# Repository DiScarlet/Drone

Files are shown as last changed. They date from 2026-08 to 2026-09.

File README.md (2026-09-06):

# Custom Drone
This is the custom 11 inch drone that I have been designing from scratch over the last few months.

Inspect the 3D Model Here: [autode.sk/4qQeJi8](https://autode.sk/4qQeJi8)

Concept Board Link: [app.idroo.com/boards/iBzdX5M0Z2](https://app.idroo.com/boards/iBzdX5M0Z2)

the goal is to make a relatively compact quadcopter that can carry a bunch of sensors and a jetson computer while still having enough thrust and flight time to actually be useful.

the electrycal connections concept was done i KiCad and the whole frame is designed in Fusion 360 and im planning to manufacture the main structural parts from carbon fiber.

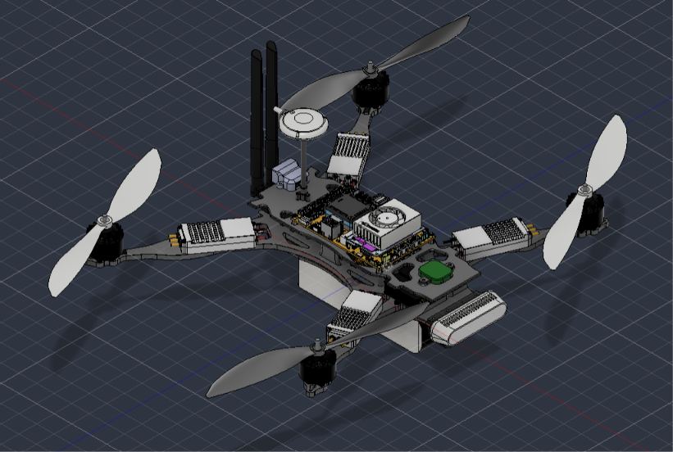
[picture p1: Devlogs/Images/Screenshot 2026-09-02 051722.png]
Full drone


## Reviewer note

Hey! If you're reviewing this, the main thing I would look at is the CAD design and how the different parts were integrated together. I tried to design the frame around the actual components instead of just making something that looks cool.

There are probably still some things I could improve, especially around weight, rigidity and aerodynamics, but I wanted to get a complete working design first and then improve it from there. Thanks for checking it out! :)

## components?

the drone is designed around:

- Pixhawk Jetson Baseboard
- Jetson Orin NX/Nano
- Holybro M10 GPS + IST8310 compass
- 4 individual ESCs
- 4 motors
- 11–12" propellers
- 6S battery
- depth camera
- 4 LiDAR sensors
- 4G communication

the idea is to have enough room for all of this without making the frame unnecessarily huge or heavy.

## why did i make this?

i wanted to build a drone where i actually designed the frame myself instead of just buying a random frame and putting electronics on it.

there were also a bunch of things i wanted to experiment with, mainly:

- custom carbon fiber frame design
- center of mass optimization
- propeller clearance
- modular arm mounting
- sensor placement
- aerodynamic testing
- fitting a jetson computer onto a relatively small drone

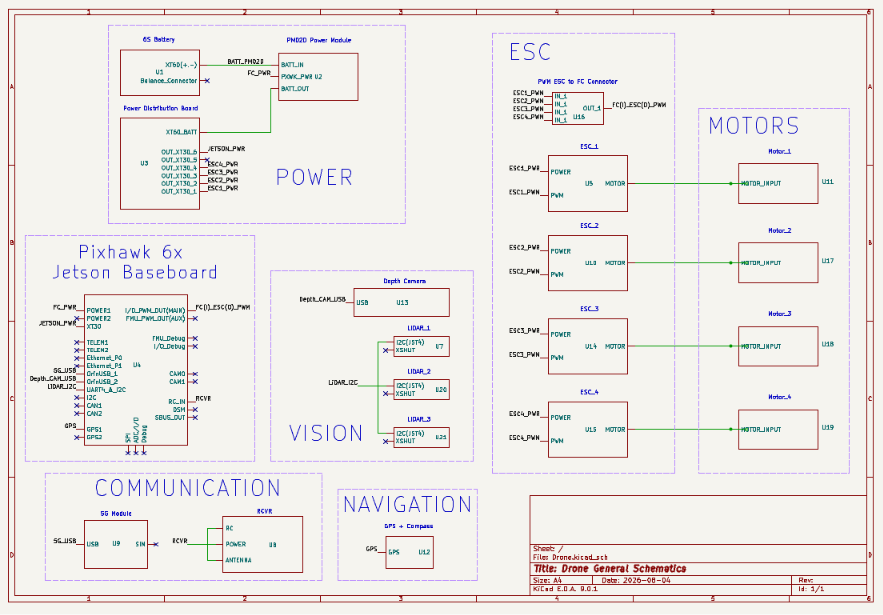
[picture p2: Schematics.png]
Schematics


also i just wanted to see how far i could take a drone design in CAD before actually building it.

## how i made it

most of the mechanical design was done in **Autodesk Fusion 360**.

i started with the overall frame dimensions and then worked from the propellers inward. this ended up being way better than trying to randomly draw the arms first because propeller clearance becomes a huge pain very quickly.

the frame went through quite a few versions.

at one point i accidentally designed a normal X layout when i was actually trying to make a deadcat layout, which was fun to figure out later.

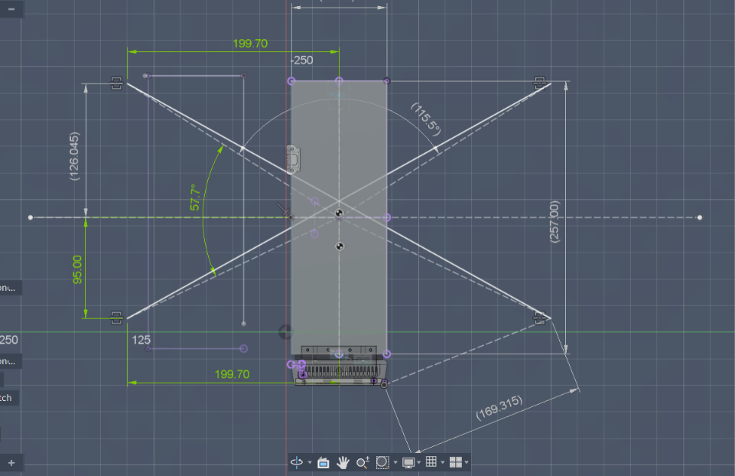
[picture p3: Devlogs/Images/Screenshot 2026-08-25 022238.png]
X


after that i worked on the arm angles, motor positions, camera clearance and center of mass.

the center of mass was another thing that took way more work than i expected. i used the actual component masses where i could and adjusted the material densities in Fusion so the CAD model would represent the real components better.

i also made the arm sections modular so they can be removed/swapped without having to completely take apart the whole drone.

## frame design

the frame has separate top, bottom and arm planes.

the bottom section carries a lot of the main structure and battery, while the top section is mainly for electronics and mounting.

i added mounting points for the different components and also added holes in the top plate to remove some material and hopefully improve airflow.

the arms also got redesigned after i realized i had completely forgotten about the ESCs.

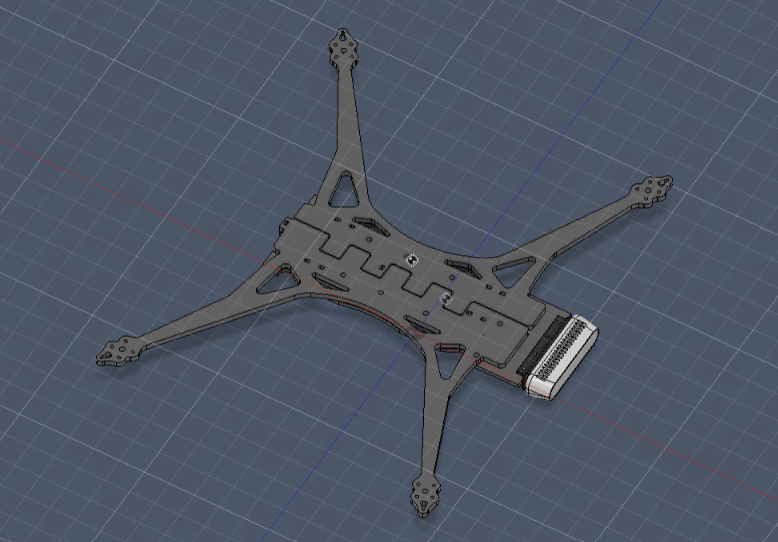
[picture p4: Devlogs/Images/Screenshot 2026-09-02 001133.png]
epic fail


yes.

i designed the arms and then remembered that the ESCs probably needed somewhere to go.

so i had to redo part of the arm design and integrate the ESC mounting properly.

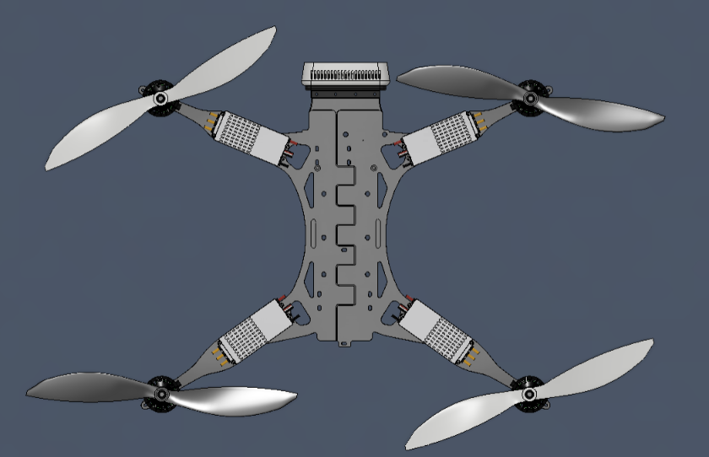
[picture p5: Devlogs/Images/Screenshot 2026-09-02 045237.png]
top view


## center of mass

the current estimated drone mass is around **3.2 kg** including some extra allowance for wiring, heatshrink and other small stuff.

i was aiming for roughly a **2.3:1 thrust-to-weight safety ratio**, which gives a target total thrust of around 7.4 kg.

that means around 1.9–2.0 kg of thrust per motor.

the battery position is also being used as one of the main ways to adjust the final center of mass instead of just adding random ballast weights.

## CFD

i am also testing the final drone design using CFD. But more experimentation are for the future.

## some pictures

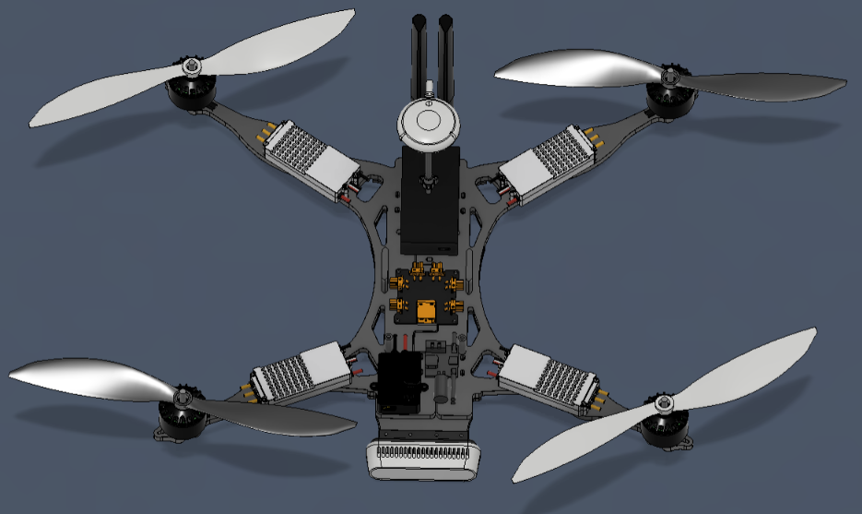
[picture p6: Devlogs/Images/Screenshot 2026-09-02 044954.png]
top


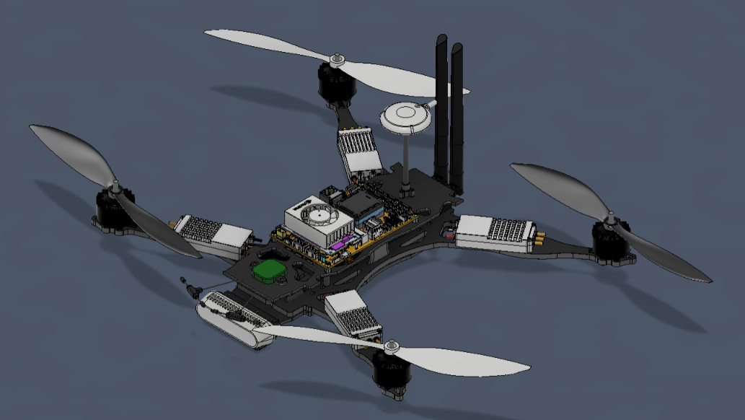
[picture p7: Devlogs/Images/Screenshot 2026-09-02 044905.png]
side view


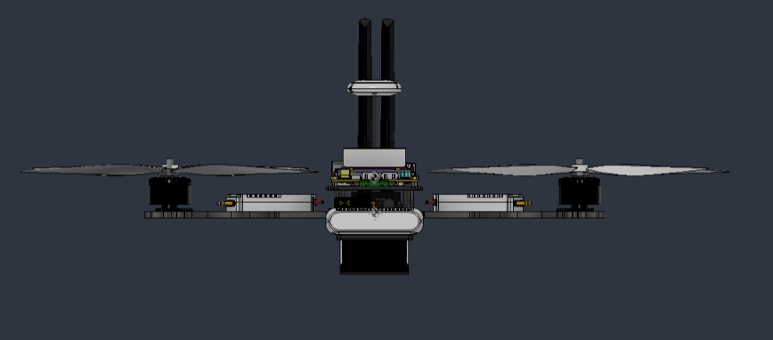
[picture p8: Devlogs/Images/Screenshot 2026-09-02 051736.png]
front view


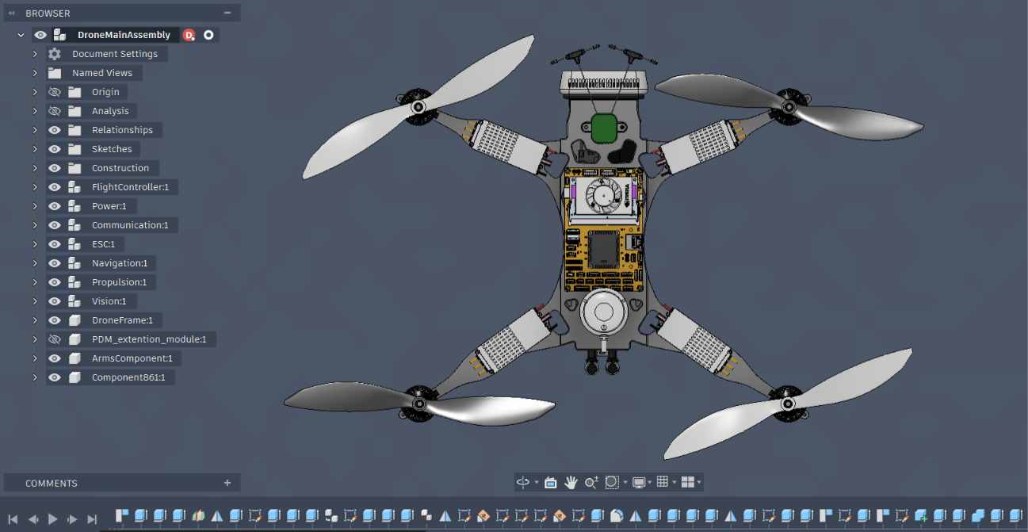
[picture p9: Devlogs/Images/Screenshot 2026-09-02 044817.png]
top 2


arms plane

lower plane

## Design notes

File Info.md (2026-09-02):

Pixhawk6c size: https://docs.holybro.com/autopilot/pixhawk-6c/dimensions
Link to the board where i drew the concept : https://app.idroo.com/boards/iBzdX5M0Z2
Sample wiring: https://docs.px4.io/v1.16/assets/power2_one_big_battery_external_ubec.DHp-01JE.png
Sample power routing:https://docs.px4.io/main/assets/pixhawk6x_wiring_diagram.BTILi51L.png
Motor: https://ueeshop.ly200-cdn.com/u_file/UPAH/UPAH113/2411/photo/3f3ab78710.jpg?x-oss-process=image/format,webp

Link to the board where i drew the concept : https://app.idroo.com/boards/iBzdX5M0Z2

BEFORE START DONT FORGT for lidar ; XSHUT pins (recommended)

The VL53L1X has an XSHUT (shutdown) pin.

At startup:

Hold sensors 2 and 3 in reset.
Initialize sensor 1 and change its I²C address.
Release sensor 2, initialize it, assign a new address.
Release sensor 3, initialize it, assign a new address.

This is the method recommended by ST.

Deadcat dorne arms anle configuartions. 
for Intel RealSense D435i 
Depth Sensor FOVT (slightly to the right)
    Horizontal: 87° 
RGB Sensor FOV
    Horizontal: 69°

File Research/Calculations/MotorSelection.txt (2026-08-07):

Info from Components.csv

Total component weight:
175 + 700 + 185 + 40 + 50 + 58.1×4 + 117×4 + 40×4 + 32 + 4.668 + 72 + 2.4×3 + 700 + 100 + 3×5 + 30
= 2971.268 g ≈ 3.0 kg

Estimated additional weight:
- Wiring
- Heatshrink
- Connectors
- Safety margin

≈ 200 g

Estimated total drone weight:
3.2 kg

Target thrust-to-weight ratio:
2.3 : 1

Required total thrust:
3.2 × 2.3 = 7.36 kg ≈ 7.4 kg

Required thrust per motor:
7.4 / 4 = 1.84 kg

Target thrust per motor:
≈ 2 kg

Design targets:
- Propeller size: 12"
- Number of blades: 2
- Battery: 6S LiPo
- Motor KV: 350–700 KV
- Priority: Efficiency / Long flight time
- Propeller material: Carbon-reinforced nylon

ESC requirements:
- Continuous current: 60 A
- Peak current: 80 A

Current motor candidate:
T-Motor MN4012 Multirotor Fixed Wing UAV Motor, 480 KV
https://cdn.shopify.com/s/files/1/0063/3946/1231/files/20250313160517.png?v=1741853160

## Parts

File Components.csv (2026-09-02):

Category | Model | Manufacturer Dimensions (mm) | Mass(gr/per 1) | Manufacturer / Buy Link
Flight Controller | Holybro Pixhawk Jetson Baseboard + Pixhawk 6X (with Jetson Orin NX) | 126 x 80 x 38.6 | 175 | https://docs.holybro.com/autopilot/pixhawk-baseboards/pixhawk-jetson-baseboard/dimension-and-weight
Power | Tattu 6S 6000–8000 mAh LiPo (XT60) | 165 x 45 x 43 | 700 | https://www.foxtechfpv.com/tattu-6s-5000mah-lipo-battery.html
Power | Holybro PM02D HV Power Module | 25 x 25 x 10 | 185 | https://docs.holybro.com/power-module-and-pdb/power-module-comparison | https://holybro.com/products/pm02d-power-module
Power | Holybro Power Distribution Board (PDB) 60A | 50 x 50 x 8 | 40 | https://shop.thebioniceye.co.uk/products/holybro-60a?variant=48882750226625
Power | Holybro UBEC 12A | 48 x 33.6 x 16.3 | 50 | https://holybro.com/products/ubec-12a
ESC | T-MOTOR ALPHA 60A 12S V1.2 | 32.5 x 80.2 x 16 | 73 | https://uav-en.tmotor.com/2018/alpha_1023/161.html
ESC-Connectors | CUSTOM NOARD LIKE Holybro PWM EXT Board*2 | 30.5 x 30.1 x 10 | 10 | https://holybro.com/collections/flight-controller-accessories/products/pwm-ext-board
Propulsion | BrotherHobby Tornado T5 3115 Pro Motor 640KV | 37.50 x 37.50 x 25.60 | 115.50 | https://www.brotherhobbystore.com/tornado-t5-3115-pro-motor-p0088-p0088.html
Propulsion | Three-blade folding propeller 9453 | 279 x 178 x 14.3 | 26.1 | https://www.masterairscrew.com/products/gf-series-11x7-propeller
Navigation | Holybro M10 GPS (IST8310 Compass) | 50 x 50 x 14.4 | 32 | https://holybro.com/products/m10-gps
Communication | RadioMaster RP3 ELRS Receiver | 22 x 13 x 4 | 4.6 | https://radiomasterrc.com/products/rp3-expresslrs-2-4ghz-nano-receiver
Vision | Intel RealSense D435i | 90 x 25 x 25 | 72 | https://www.realsenseai.com/products/depth-camera-d435i/
Vision | ST VL53L1X Lidar (x3) | 25 x 10.7 x 3.2 | 2.4 | https://holybro.com/products/st-vl53l1x-lidar
Structure | Custom Carbon Fiber Frame | 430–450 mm wheelbase | 700 | N/A (custom)
Structure | Custom Landing Gear | Custom | 200 | N/A (custom)
Fasteners | M3 Socket Head Screws + Aluminum Standoffs | Various | 100 | https://www.mcmaster.com/metric-fasteners/
Connectors | XT30 male * 4 (for ESC - PDB conn) | 12 x 11 x 6 | 3 | https://originhobbies.com/fi/shop/helikopterin-osat-2/omphobby-spare-parts/omp-m2-parts/amass-xt30-male-connector/
Connectors | USB type A male to female (for 5G - FC conn) | - | 30 | https://www.gigantti.fi/product/palvelut-ja-lisavarusteet/kaapelit-ja-liitettavyys/virtajohdot/delock-extension-cable-usb-30-type-a-male-usb-30-type-a-female-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
Connectors | MICROBARB® BRASS - SHORT LENGTH - M3 | - | 50 | https://www.clipcarbono.com/en/threaded-inserts/2152-microbarb-brass-short-length-m3.html
Communication | D-Link D501 5G USB Adapter | 95 x 41 x 22.5 | 68 | https://www.dlink.com/fi/fi/products/d501-5g-nr-usb-adapter
OR
(Communication | LTE EG25-G Mini PCIe | 51 x 30 x 4.9 | 9.8 | https://www.quectel.com/product/lte-eg25-g-mpcie/
AND
Communication-Connectors | Mini PCI-E PCI-Express to USB Adapter | 89 x 45 x 18 | 100 | https://tietokonekauppa.fi/products/2759393/Verkkotuotteet/Reitittimet_ja_tukiasemat/4G_LTE_modeemit_reitittimet/BXAW_AB_XS/Mini_PCI_E_PCI_Express_to_USB_Adap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

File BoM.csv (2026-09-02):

Category | Model | Manufacturer | Quantity | Dimensions (mm) | Mass (g/unit) | Approx. Unit Cost (EUR) | Approx. Total Cost (EUR) | Manufacturer / Buy Link | Notes
Flight Controller | Holybro Pixhawk Jetson Baseboard + Pixhawk 6X + Jetson Orin NX | Holybro | 1 | 126 x 80 x 38.6 | 175.0 | 650.0 | 650 | https://docs.holybro.com/autopilot/pixhawk-baseboards/pixhawk-jetson-baseboard/dimension-and-weight | Core flight controller and companion computer platform
Power | Tattu 6S 6000–8000 mAh LiPo (XT60) | Tattu | 1 | 165 x 45 x 43 | 700.0 | 100.0 | 100 | https://www.foxtechfpv.com/tattu-6s-5000mah-lipo-battery.html | Main propulsion battery; price is approximate
Power | Holybro PM02D HV Power Module | Holybro | 1 | 25 x 25 x 10 | 185.0 | 35.0 | 35 | https://holybro.com/products/pm02d-power-module | Monitors and supplies flight-controller power
Power | Holybro Power Distribution Board (PDB) 60A | Holybro | 1 | 50 x 50 x 8 | 40.0 | 25.0 | 25 | https://shop.thebioniceye.co.uk/products/holybro-60a | Distributes battery power to ESCs
Power | Holybro UBEC 12A | Holybro | 1 | 48 x 33.6 x 16.3 | 50.0 | 25.0 | 25 | https://holybro.com/products/ubec-12a | Regulated power for onboard electronics
ESC | T-MOTOR ALPHA 60A 12S V1.2 | T-MOTOR | 4 | 32.5 x 80.2 x 16 | 73.0 | 55.0 | 220 | https://uav-en.tmotor.com/2018/alpha_1023/161.html | One ESC per motor
ESC-Connectors | CUSTOM BOARD LIKE Holybro PWM EXT Board | Holybro/custom | 2 | 30.5 x 30.1 x 10 | 10.0 | 15.0 | 30 | https://holybro.com/collections/flight-controller-accessories/products/pwm-ext-board | Interface/extension boards for ESC signal connections
Propulsion | BrotherHobby Tornado T5 3115 Pro Motor 640KV | BrotherHobby | 4 | 37.50 x 37.50 x 25.60 | 115.5 | 35.0 | 140 | https://www.brotherhobbystore.com/tornado-t5-3115-pro-motor-p0088-p0088.html | One motor per arm
Propulsion | Three-blade folding propeller 9453 | Master Airscrew | 4 | 279 x 178 x 14.3 | 26.1 | 15.0 | 60 | https://www.masterairscrew.com/products/gf-series-11x7-propeller | One propeller per motor; verify exact 9453 variant/pitch compatibility
Navigation | Holybro M10 GPS (IST8310 Compass) | Holybro | 1 | 50 x 50 x 14.4 | 32.0 | 45.0 | 45 | https://holybro.com/products/m10-gps | GPS and compass
Communication | RadioMaster RP3 ELRS Receiver | RadioMaster | 1 | 22 x 13 x 4 | 4.6 | 25.0 | 25 | https://radiomasterrc.com/products/rp3-expresslrs-2-4ghz-nano-receiver | RC telemetry/control receiver
Vision | Intel RealSense D435i | Intel RealSense | 1 | 90 x 25 x 25 | 72.0 | 180.0 | 180 | https://www.realsenseai.com/products/depth-camera-d435i | Front depth/vision camera
Vision | ST VL53L1X Lidar | STMicroelectronics | 3 | 25 x 10.7 x 3.2 | 2.4 | 10.0 | 30 | https://holybro.com/products/st-vl53l1x-lidar | Three short-range distance sensors
Structure | Custom Carbon Fiber Frame | Custom | 1 | 430–450 mm wheelbase | 700.0 | 150.0 | 150 | N/A (custom) | Custom airframe
Structure | Custom Landing Gear | Custom | 1 | Custom | 200.0 | 40.0 | 40 | N/A (custom) | Custom landing gear
Fasteners | M3 Socket Head Screws + Aluminum Standoffs | Various | 1 | Various | 100.0 | 30.0 | 30 | https://www.mcmaster.com/metric-fasteners/ | Assorted mounting hardware
Connectors | XT30 male | Amass | 4 | 12 x 11 x 6 | 3.0 | 1.5 | 6 | https://originhobbies.com/fi/shop/helikopterin-osat-2/omphobby-spare-parts/omp-m2-parts/amass-xt30-male-connector/ | ESC-to-PDB connectors
Connectors | USB 3.0 Type-A male to female extension cable | Delock/Generic | 1 | - | 30.0 | 10.0 | 10 | https://www.gigantti.fi/product/palvelut-ja-lisavarusteet/kaapelit-ja-liitettavyys/virtajohdot/delock-extension-cable-usb-30-type-a-male-usb-30-type-a-female-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 | USB connection for 5G adapter
Connectors | MICROBARB Brass Short Length M3 | ClipCarbono | 1 | - | 50.0 | 10.0 | 10 | https://www.clipcarbono.com/en/threaded-inserts/2152-microbarb-brass-short-length-m3.html | Threaded inserts for frame
Communication | D-Link D501 5G USB Adapter | D-Link | 1 | 95 x 41 x 22.5 | 68.0 | 120.0 | 120 | https://www.dlink.com/fi/fi/products/d501-5g-nr-usb-adapter | 5G cellular connectivity; alternative to EG25-G setup

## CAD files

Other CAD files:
CAD/Components/Navigation/GPS-M8N-M9N-full_asm.stp
CAD/FULL_ASSEMBLY/DroneMainAssemblyStep.step
CAD/FULL_ASSEMBLY/DroneNoFCAssembly.step
CAD/Components/Communication/WiFi Antenna.STEP
CAD/Components/ESC/PDM_extention_module.STEP
CAD/Components/FlightController/Pixhawk-Jetson-Baseboard-3D.stp
CAD/Components/Power/Hobbywing UBEC 12A v4.step
CAD/Components/Propulsion/BrotherHobby_Tornado_T5_Pro_3113_640.step
CAD/Components/Vision/Lidar ST VL53L1X.STEP
CAD/Components/Communication/D-Link_D501_5G_USB_ Adapter.step
CAD/Components/ESC/T-Motor ESC Alpha 60A HV V1.2.step
CAD/Components/Power/PM02D.STEP
CAD/Components/Propulsion/11x4.7_pusher_9mm.STEP
CAD/Components/Vision/RealSense_D435.SLDPRT
CAD/Components/Communication/Radiomaster RP3 Simplified.step
CAD/Components/Power/Tattu_6S_8000mAh_25C.step
CAD/Components/Power/18069A-PDB_asm.stp

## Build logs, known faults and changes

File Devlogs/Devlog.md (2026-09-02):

# Drone Development Log

## Day 1: Research and Initial Design

Concept board: <https://app.idroo.com/boards/iBzdX5M0Z2>  
Drone General Design, Part 1: <https://lapse.hackclub.com/timelapse/2bgpf7khk9ri>

This project turned out to be much harder than I initially expected. At first, I thought designing a drone frame would mostly be about getting the dimensions right and fitting the electronics inside. Instead, almost every design choice affects several others. The frame layout determines the electronics placement, which changes the center of gravity, battery location, cooling, cable routing, and manufacturing process.

### Reference Frames

The first step was reviewing existing drones that meet my requirements: a 10-inch quadcopter capable of carrying a companion computer and depth camera while running on a 4–6S battery.

I chose the **Holybro X500 V2 / PX4 Vision Dev Kit V1.5** as my primary reference. I also reviewed the iFlight Helion 10 and AOS UL10 V5, but the Holybro platform is closer to the autonomous robotics platform I want to build.

Useful references:

- <https://docs.px4.io/main/en/frames_multicopter/holybro_x500v2_pixhawk6c>
- <https://docs.px4.io/main/assets/payloads_x500v2.BlKS32-f.png>
- <https://ntu-aris.github.io/ntu_viral_dataset/images/hardware.jpg>
- <https://docs.px4.io/main/assets/hero_image.DGHv_vvL.png>

The Holybro design also helped me understand how professional development drones package their electronics.

### Initial Design Decisions

The drone will use an X-configuration quadcopter layout. I chose this layout because it provides symmetrical flight characteristics and is common in autonomous drones. It will use a **Pixhawk 6X with the Holybro Jetson Baseboard**, allowing the flight controller and companion computer to work together as one stack.

This is an autonomous robotics platform rather than a racing drone. A depth camera such as an Intel RealSense or Luxonis OAK-D already provides RGB and depth sensing, so a separate forward-facing camera may not be necessary. The drone will also include GPS, an RC receiver, telemetry, and possibly a video transmitter.

### Mechanical Analysis

Before committing to frame dimensions, I want to perform basic engineering calculations instead of relying purely on intuition. These will include a stress analysis of the arms and a simple drop-test calculation for rough landings or crashes.

References:

- <https://sites.bu.edu/uav/files/2017/11/Frames.pdf>
- <https://blog.uavmodel.com/how-to-design-and-3d-print-custom-drone-frames/>

### Material Selection

Carbon fiber is the obvious final material because of its excellent stiffness-to-weight ratio. I will probably prototype using cheaper materials first, verify the fit, and manufacture the final version from carbon fiber later.

### Notes and Decisions

- A standard 10-inch propeller has a diameter of 254 mm, which is a useful starting point for estimating the wheelbase.
- The complete Pixhawk 6X, Jetson Baseboard, Orin NX, and heatsink assembly is approximately **126 × 80 × 39–45 mm**. This almost determines the minimum size of the center frame.
- I chose four separate ESCs instead of one 4-in-1 ESC. Separate ESCs are easier to replace, distribute heat better, and suit a research platform where reliability matters more than saving a few grams.
- The arms will be sandwiched between the upper and lower carbon plates.
- The ESCs, switching regulators, and high-current battery wiring are the main sources of electrical interference, rather than the Jetson itself.

The frame concept uses two levels. The Jetson Baseboard, telemetry, and receiver will be mounted on the upper deck. The lower section will contain the power distribution board and four ESCs. The battery will be mounted underneath, the depth camera will sit at the front, and the GPS will probably be mounted on a rear mast to reduce interference.

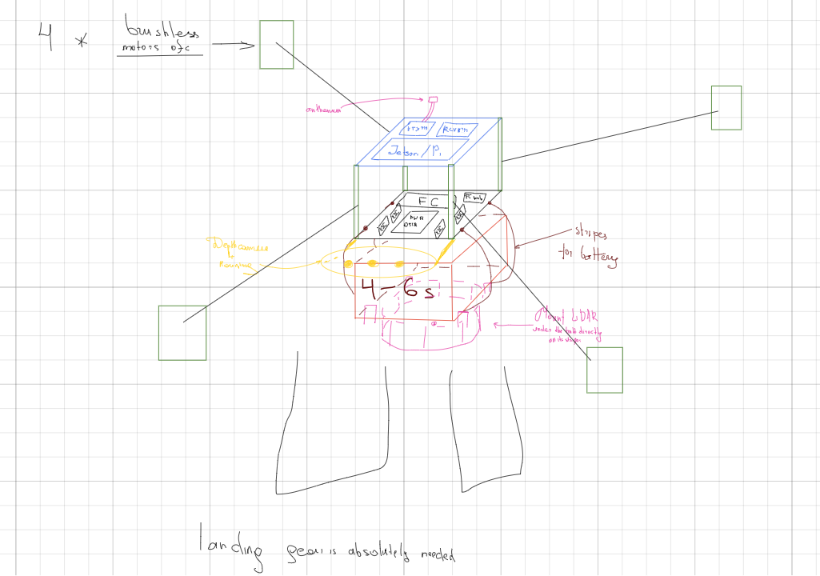
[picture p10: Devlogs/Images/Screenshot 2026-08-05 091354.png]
Design 1


At this stage, I expect many decisions to change. The goal is to make enough informed choices to begin modeling in Fusion 360 rather than researching indefinitely.

## Day 1, Part 2: Second Design Concept

Drone General Design, Part 2: <https://lapse.hackclub.com/timelapse/HdxbJGZdjz3A>

I created a second design concept and placed the major components at approximately their real dimensions. The goal was to check whether everything could realistically fit inside the central body before starting the detailed CAD work.

The battery remains underneath the frame. The upper section is reserved for the Pixhawk 6X, Jetson Baseboard, cellular radio, RC receiver, GPS/compass, and other electronics. The four separate ESCs are placed closer to the arms to reduce motor-wire length and simplify replacement.

The Pixhawk and Jetson assembly is larger than expected, so the center frame will probably need to be larger than originally planned. Cable routing, cooling, and maintenance access are just as important as fitting the components themselves.

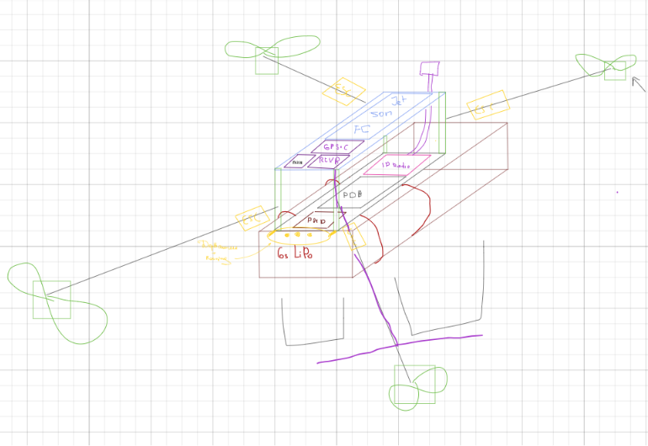
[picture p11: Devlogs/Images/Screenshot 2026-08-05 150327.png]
Design 2


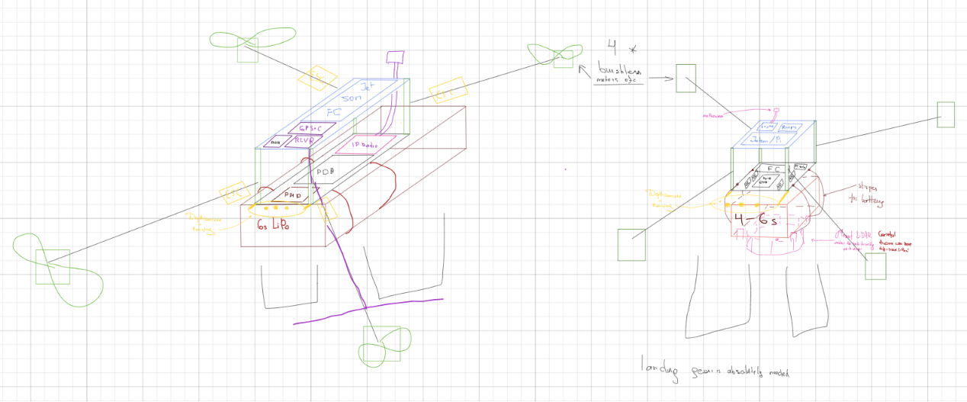
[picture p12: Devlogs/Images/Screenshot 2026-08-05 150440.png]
Design 1 and Design 2 side by side


**TODO:** Plan the wiring.

## Day 2: Electronics Architecture and Schematic

Drone General Design, Part 3: <https://lapse.hackclub.com/timelapse/EFwJGuFalmob>  
KiCad Symbols: <https://lapse.hackclub.com/timelapse/CfTy0n8EebXS>  
Routing and Components: <https://lapse.hackclub.com/timelapse/v2zys5-Etka2>

I worked on the electronics and communication architecture. After comparing telemetry radios with 4G/5G communication, I decided to move toward a 4G/5G solution.

I created the initial BOM and updated several components as I found options that fit the project better. For KiCad, I made simplified symbols that expose high-level connectors instead of every individual pin. This keeps the schematic focused on system architecture rather than PCB-level detail.

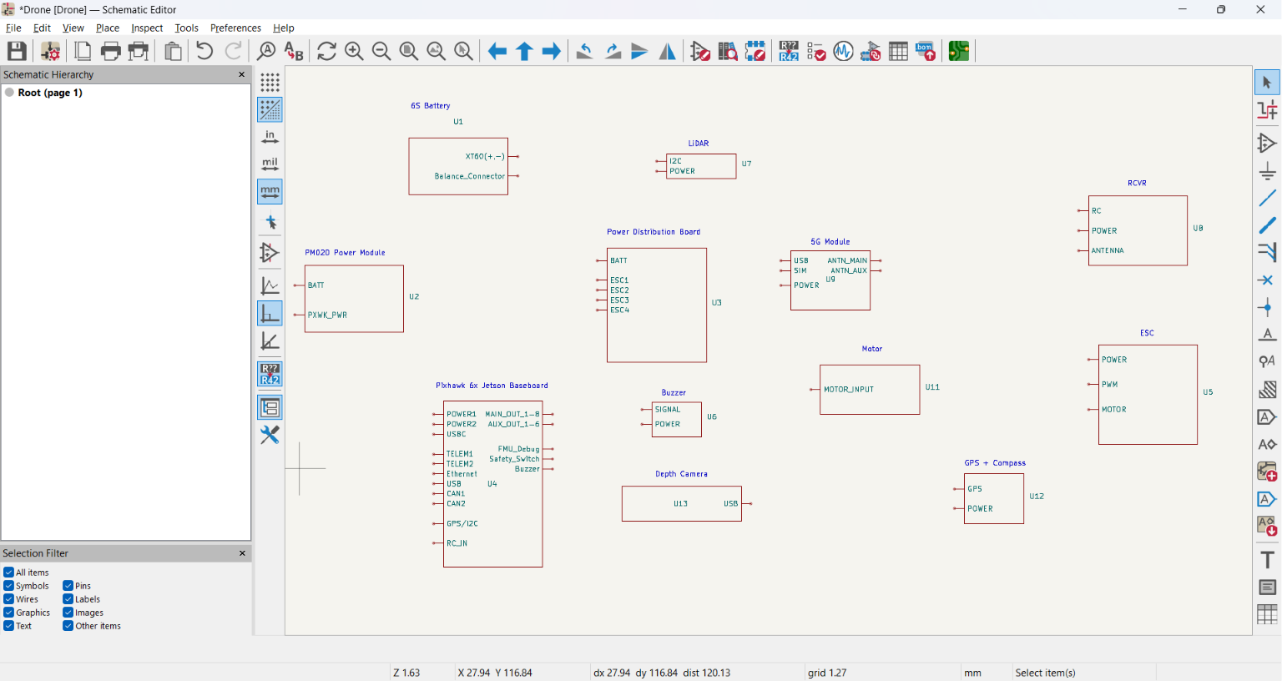
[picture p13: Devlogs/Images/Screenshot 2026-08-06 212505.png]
All new elements


I also studied the connectors and ports on the Pixhawk Jetson Baseboard.

Reference: <https://docs.px4.io/main/assets/power1_one_battery_3s_4s.BwKdxwes.jpg>

### Design Version 3

The third design iteration uses more realistic component dimensions and placements.

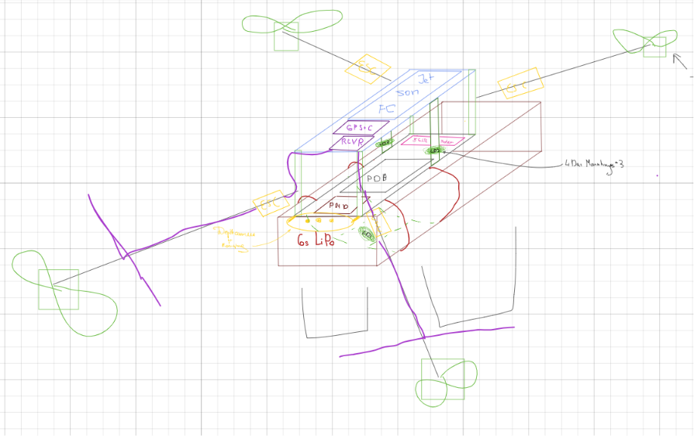
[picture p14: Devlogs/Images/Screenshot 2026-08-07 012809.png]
Design Version 3


### Schematic Version 1

The first complete system schematic is intentionally high-level. It shows how the main subsystems connect without detailing individual signals or PCB-level connections.

Schematic Version 1

Some connector and communication choices are still uncertain, so the schematic may change as the design develops. Creating it was worthwhile because it provides a map of the system before the physical wiring is finalized.

## Day 3: Real Connectors and Hardware Selection

Real Connectors: <https://lapse.hackclub.com/timelapse/CkFQIcG4ptSY>  
Finalizing Hardware Choices: <https://lapse.hackclub.com/timelapse/vVLvC90nyClp>  
Downloading and Uploading Components: <https://lapse.hackclub.com/timelapse/R_qcUxAQv0iU>  
D-Link D501 5G USB Adapter: <https://lapse.hackclub.com/timelapse/Ui7_f7U2WzdP>

I moved from theoretical hardware planning to physical placement. I placed the connectors in their approximate locations to check alignment and fit.

For propulsion, I estimated a total weight of 3.2 kg and a target thrust-to-weight ratio of 2.3:1. This requires approximately 7.4 kg of total thrust, or 1.85 kg per motor. I decided to target approximately 2 kg per motor for additional margin.

I compared 10-inch and 12-inch propeller setups using manufacturer thrust tables rather than choosing only by KV and motor size. For now, I am using 12-inch, two-blade propellers with a 6S battery and looking at motors in the 350–700 KV range.

I also downloaded 3D models for the components. Some models are approximate, but they are sufficient for checking layout. The assembly is becoming heavy for my laptop, so model optimization may be necessary.

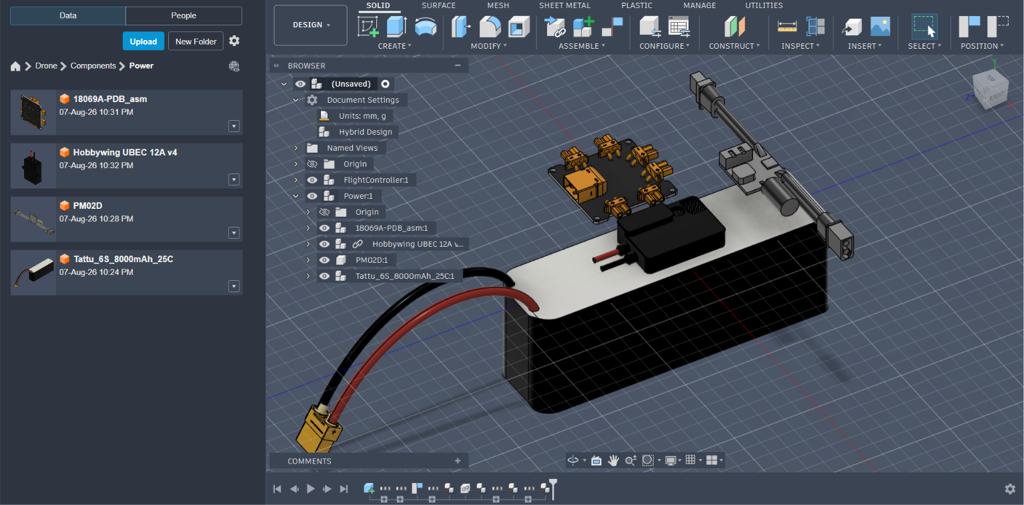
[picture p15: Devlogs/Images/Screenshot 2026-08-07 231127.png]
Power

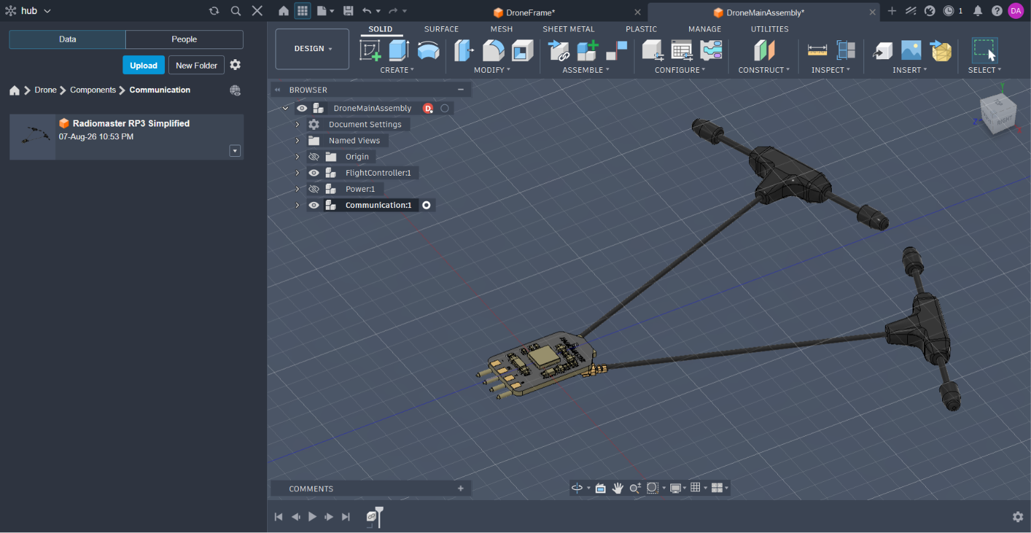
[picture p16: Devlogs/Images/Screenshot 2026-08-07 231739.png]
Communication

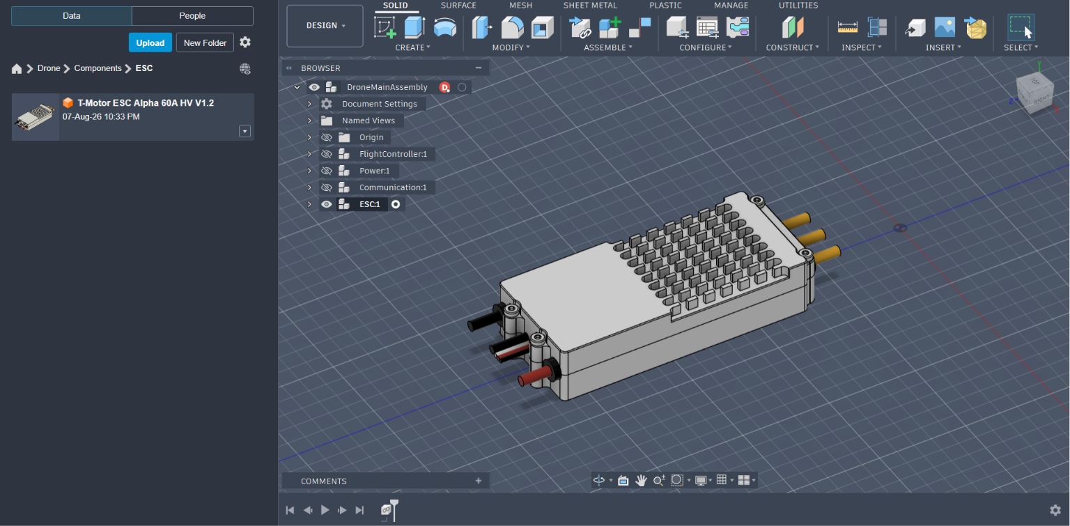
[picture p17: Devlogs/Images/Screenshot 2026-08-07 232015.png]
ESC

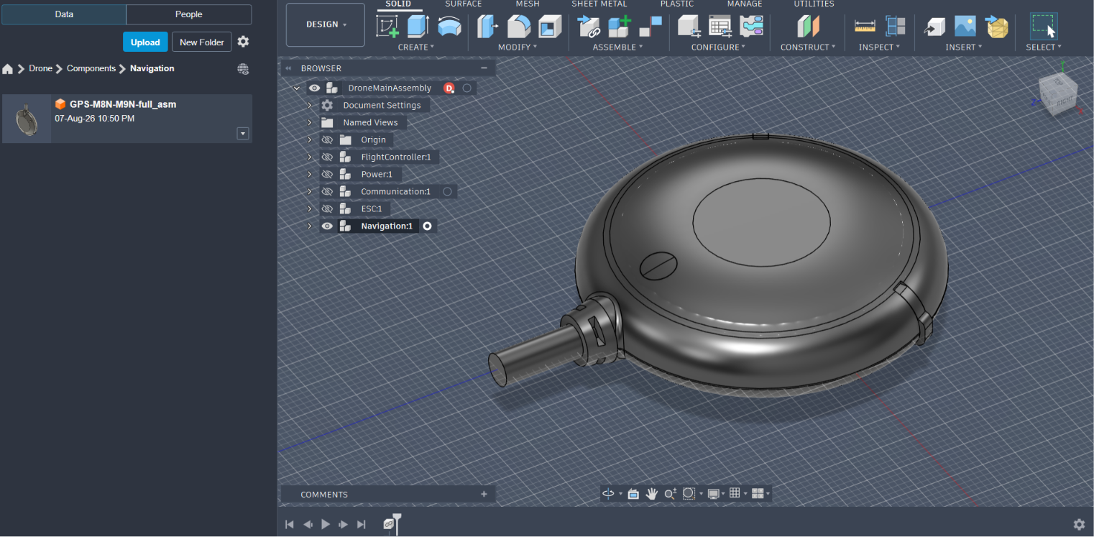
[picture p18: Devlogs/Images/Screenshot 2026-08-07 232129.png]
Navigation

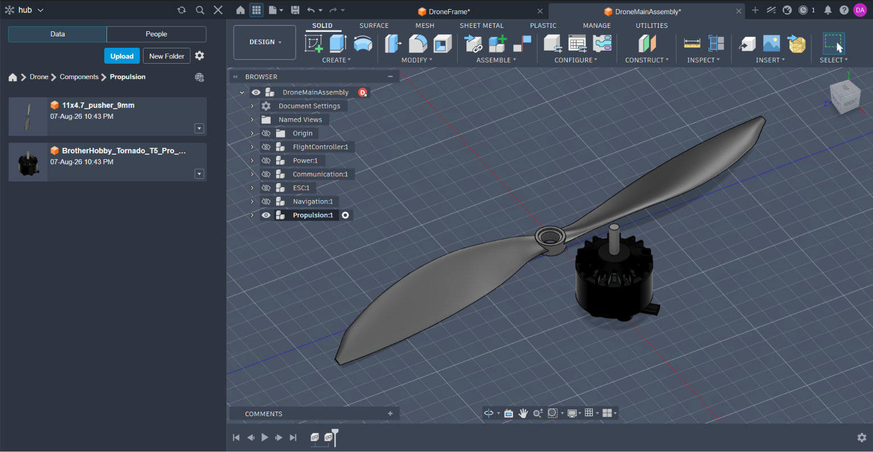
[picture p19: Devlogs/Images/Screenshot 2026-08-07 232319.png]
Propulsion

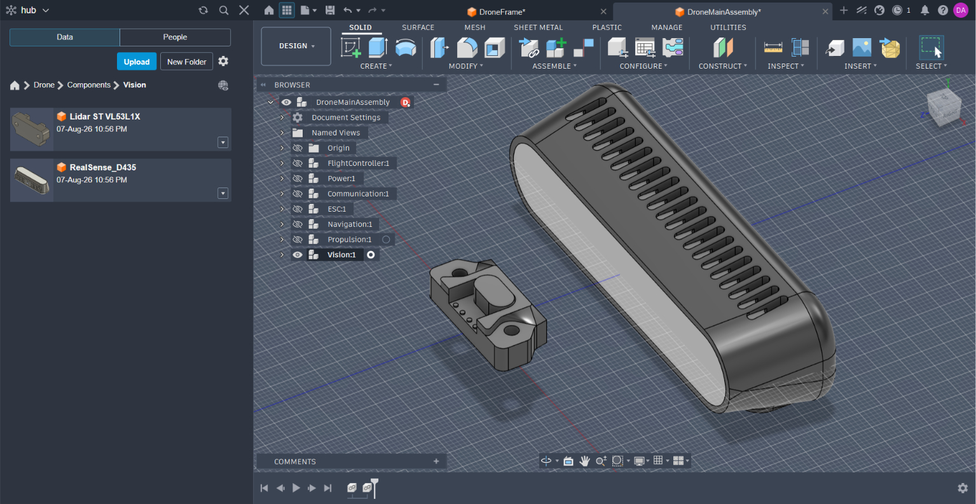
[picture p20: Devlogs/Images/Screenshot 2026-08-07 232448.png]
Vision

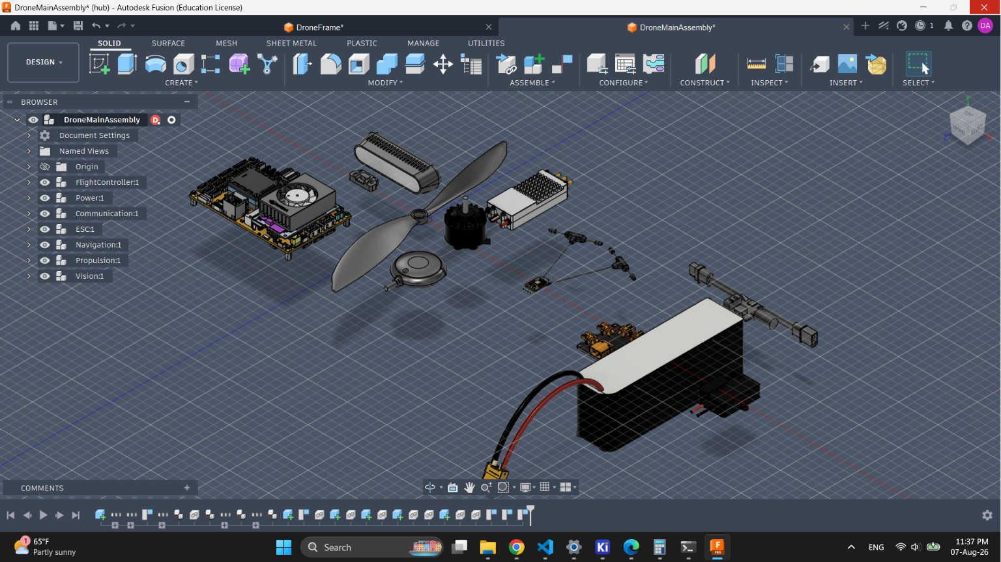
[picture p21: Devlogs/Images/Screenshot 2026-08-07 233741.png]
All components


The D-Link D501 5G USB Adapter was the only missing component, so I created an approximate model myself.

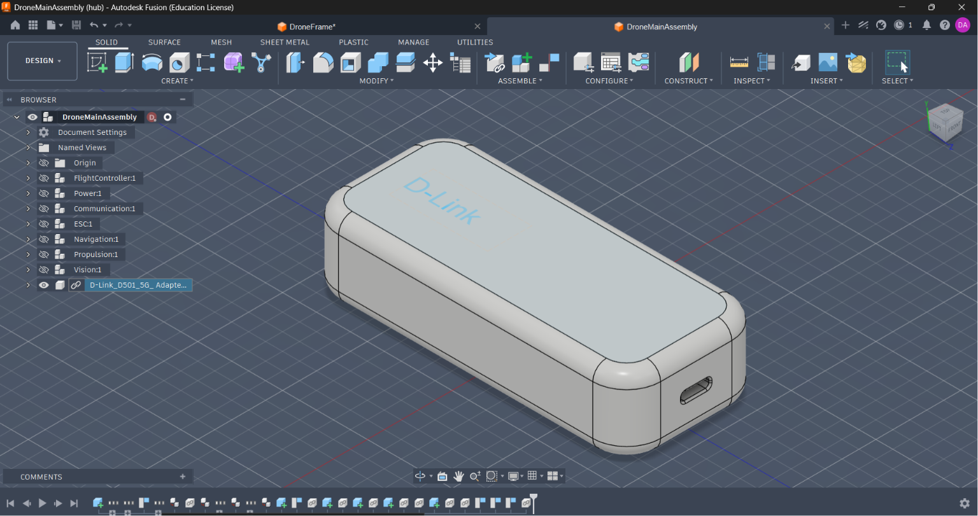
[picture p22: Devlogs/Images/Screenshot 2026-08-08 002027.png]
D-Link D501 5G USB Adapter


## Day 4: Plates and Cellular Communication

Top and Bottom Plates: <https://lapse.hackclub.com/timelapse/v_VVVfQ6t21S>

Design Version 4 started to look like an actual drone, but the bottom plate still needed work. I also realized that the D-Link 5G adapter was too large and would occupy too much space. I considered moving the UBEC or placing the cellular hardware on the upper deck.

Placing every component at its real size exposed spacing and alignment problems that were not visible in the schematic. I also learned that carbon fiber can interfere with RF signals, so antenna placement and the surrounding structure will need careful consideration.

I began investigating the smaller LTE EG25-G Mini PCIe module with a USB carrier as a possible replacement for the large USB adapter.

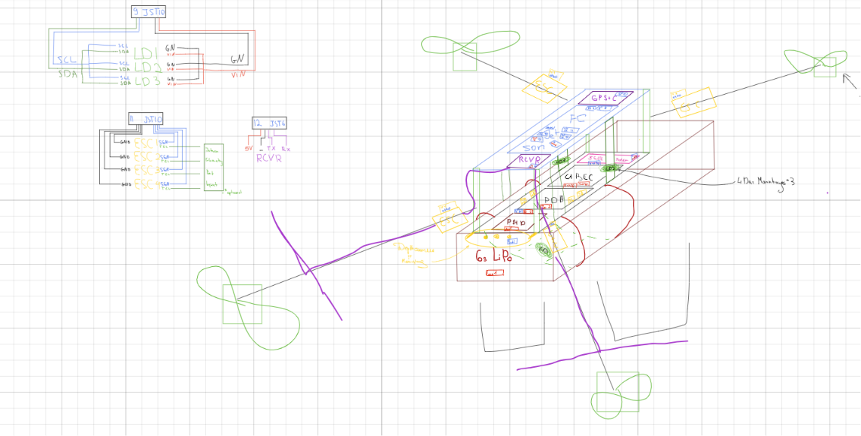
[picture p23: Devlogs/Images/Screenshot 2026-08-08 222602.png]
Design V4

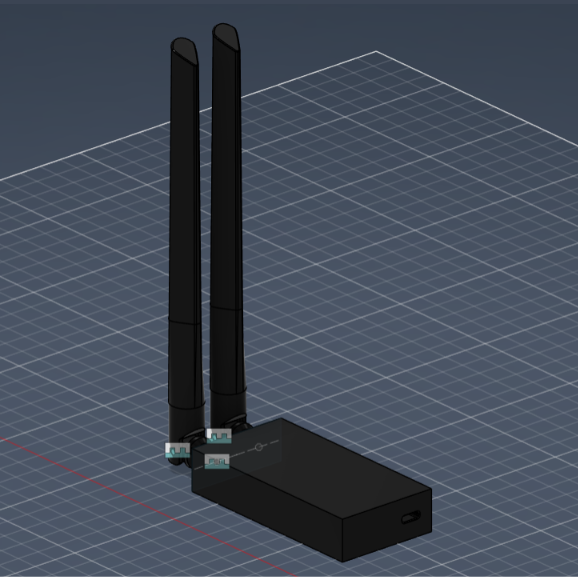
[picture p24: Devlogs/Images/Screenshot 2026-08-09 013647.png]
LTE EG25-G Mini PCIe adapter

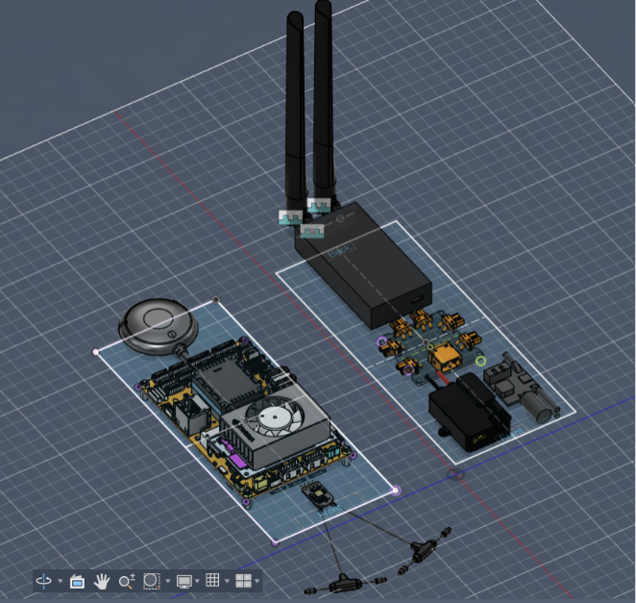
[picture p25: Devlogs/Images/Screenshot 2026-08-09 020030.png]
Top and bottom plates


## Day 5: Propulsion and Design Version 5

Design Version 5: <https://lapse.hackclub.com/timelapse/LQik73zLpkbC>

I worked on propulsion, including CW and CCW propellers, motor alignment, and model clearances.

The bottom plate must support the upper components and the battery underneath, so it may need to be thicker than the top plate. I also started using the PWM extension board, which required changes to the layout but provides a cleaner way to connect the four ESCs.

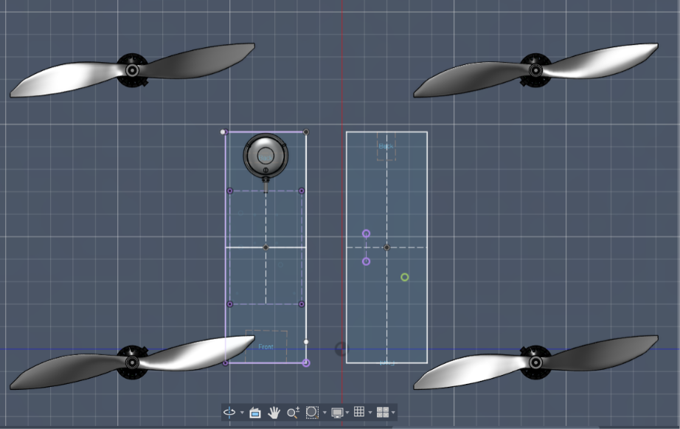
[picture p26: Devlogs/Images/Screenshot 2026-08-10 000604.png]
Propulsion elements

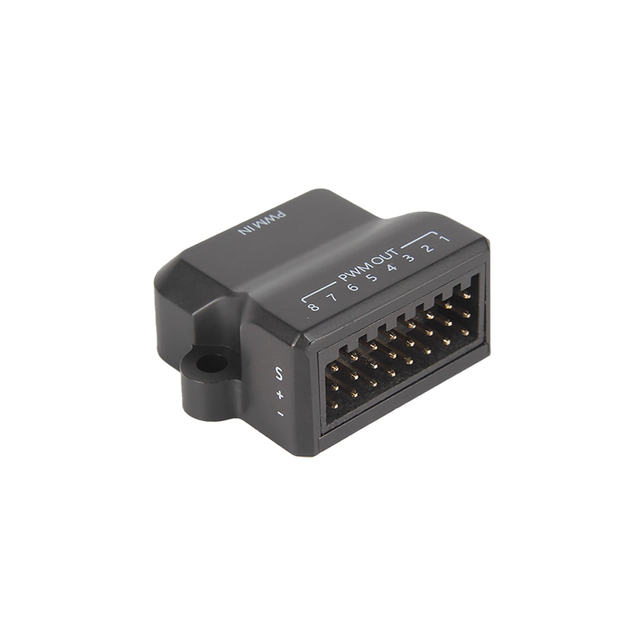
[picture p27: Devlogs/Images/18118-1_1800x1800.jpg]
PWM extension board


Remaining considerations included custom PWM connector placement, center of mass, mounting hardware, clearance checks, and battery balance.

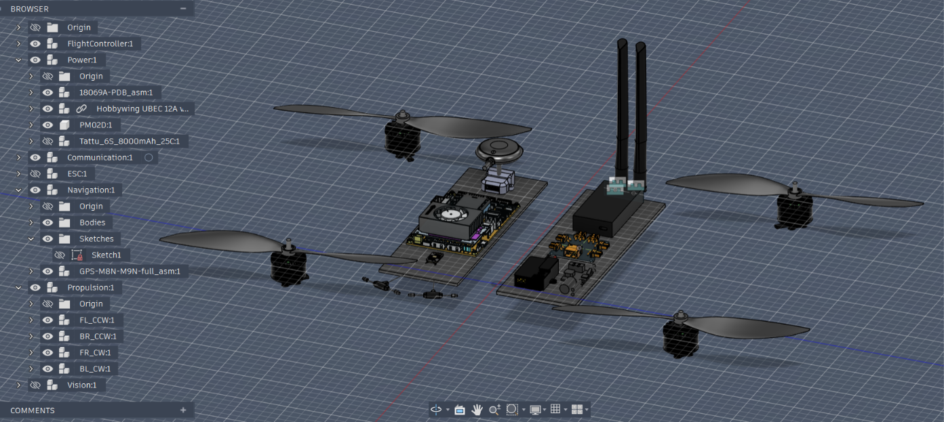
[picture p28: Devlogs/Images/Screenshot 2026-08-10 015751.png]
V5 Design Fusion

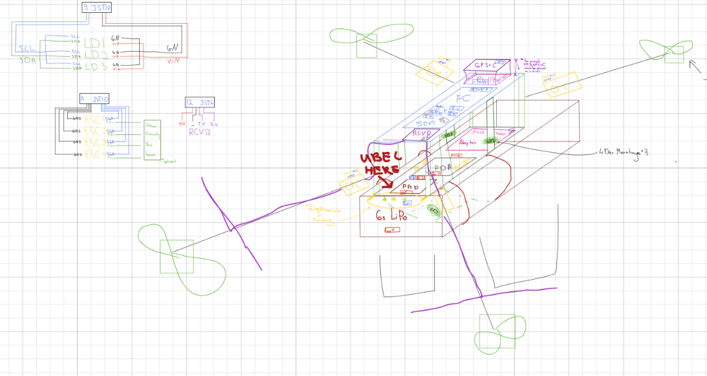
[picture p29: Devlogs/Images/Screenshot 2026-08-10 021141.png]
V5 Design Layout


## Day 6: GPS, Depth Camera Mount, and Center of Mass

I created a GPS mounting base with M2 threads and a custom mount for the depth camera.

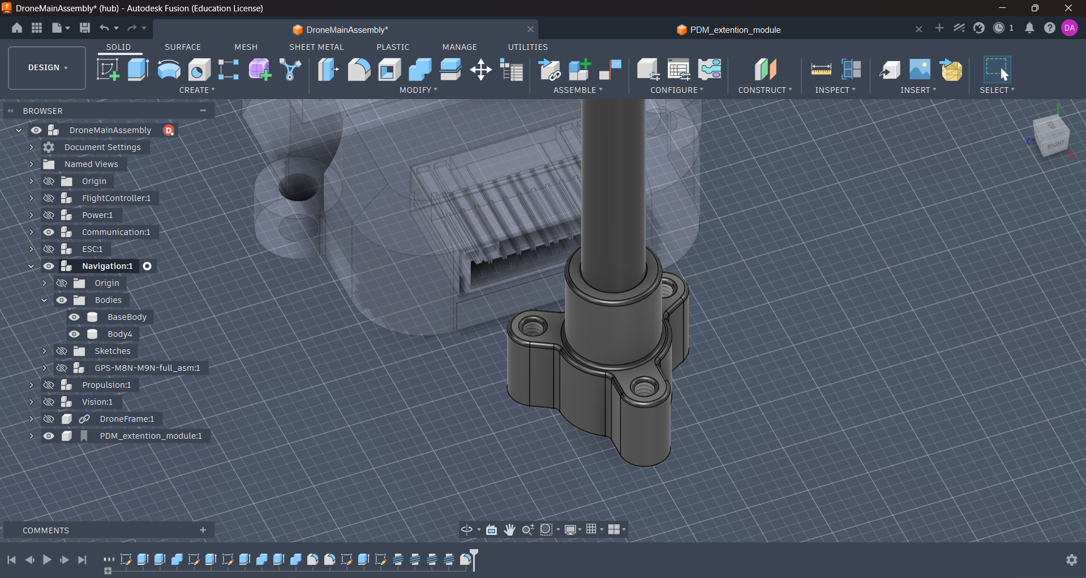
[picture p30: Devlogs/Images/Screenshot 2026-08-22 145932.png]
GPS mounting base

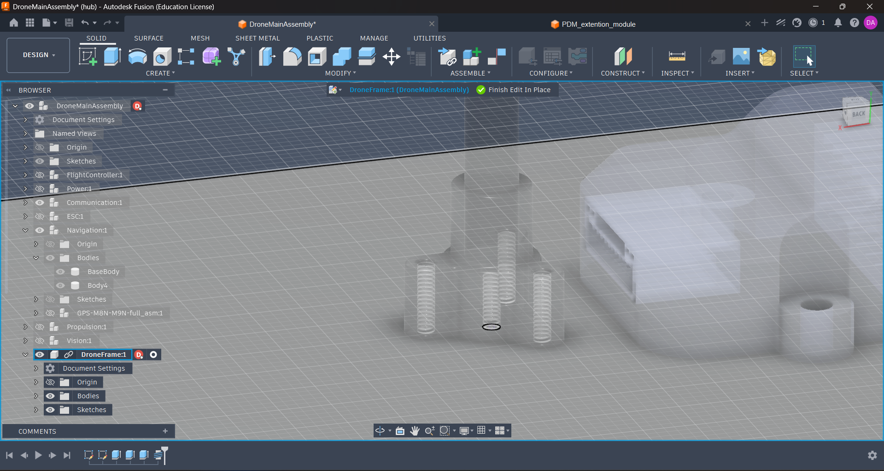
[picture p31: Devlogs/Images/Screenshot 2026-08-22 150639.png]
GPS mount with M2 threads

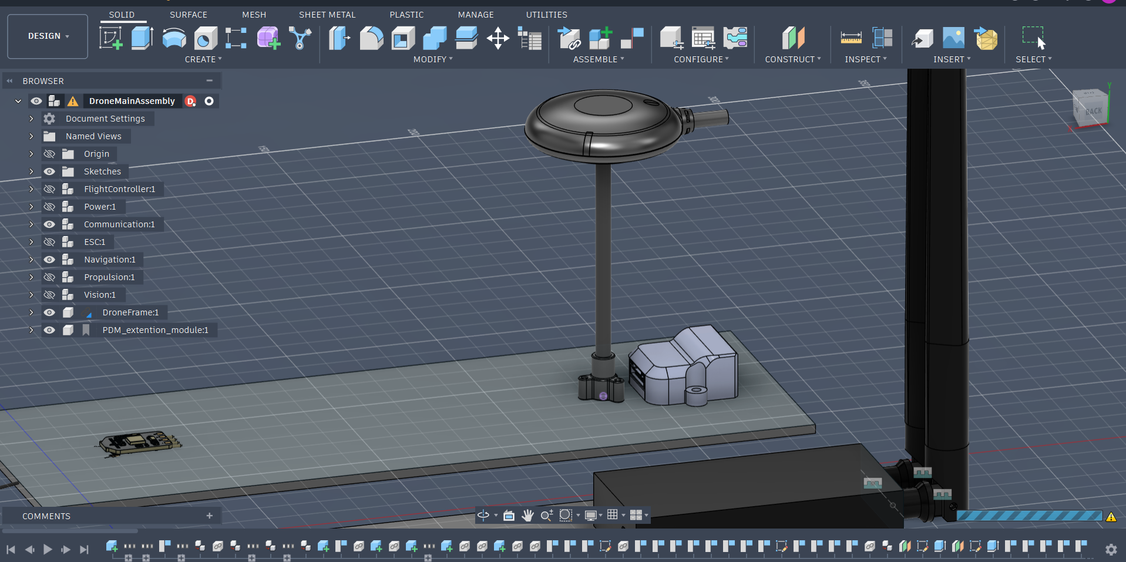
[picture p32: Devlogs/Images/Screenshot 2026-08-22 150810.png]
Full GPS view

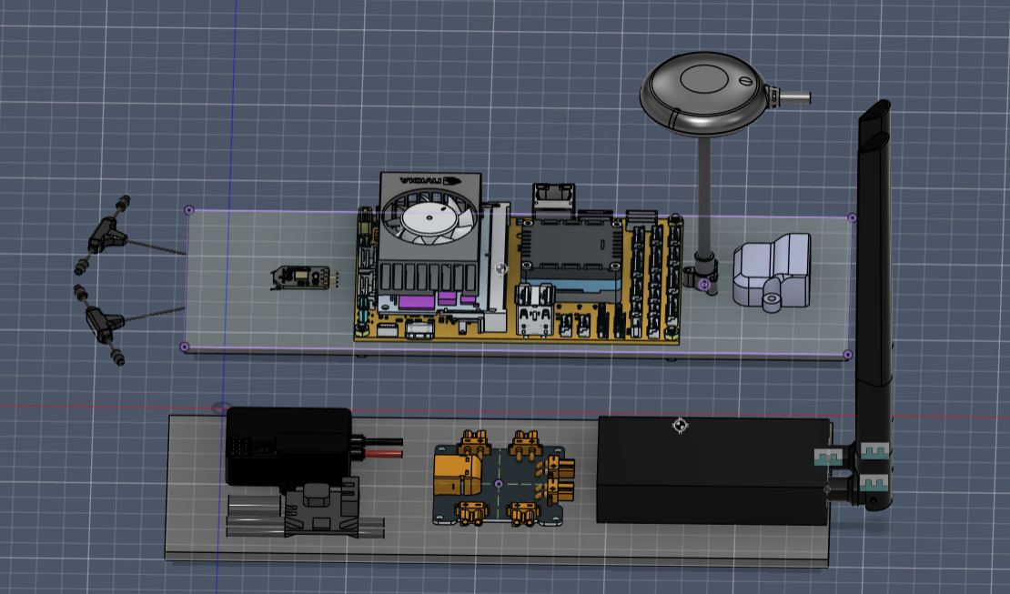
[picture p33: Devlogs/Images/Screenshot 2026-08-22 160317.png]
Initial centers of mass

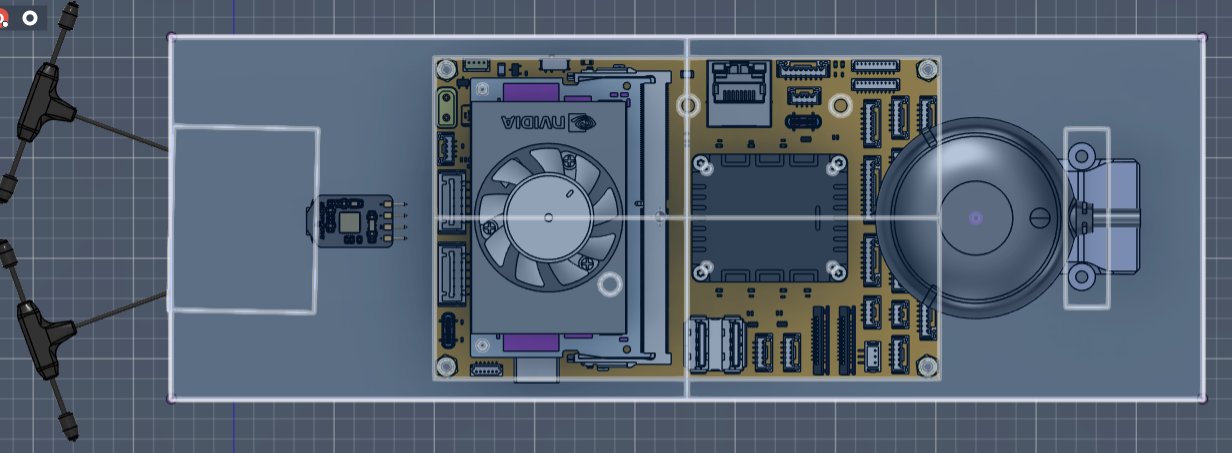
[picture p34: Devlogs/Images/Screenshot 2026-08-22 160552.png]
Top plate center of mass

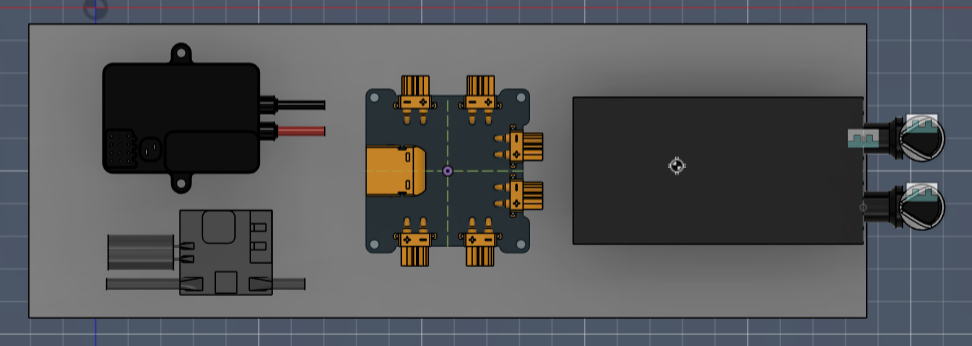
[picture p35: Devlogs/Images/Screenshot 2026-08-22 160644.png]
Lower plate center of mass


The first center-of-mass results were approximate because the models used incorrect materials and masses. I gathered the real masses, calculated the volumes of the components, and created custom materials with matching densities in Fusion 360.

I also considered using Autodesk CFD to investigate airflow and cooling. CFD may help evaluate ventilation and external airflow, but it will not replace a careful center-of-mass calculation. The most useful next steps are to model the correct masses, check the complete assembly, verify the battery position, and test cooling around the ESCs and regulators.

I finished the depth-camera mount and added ventilation holes and mounting points.

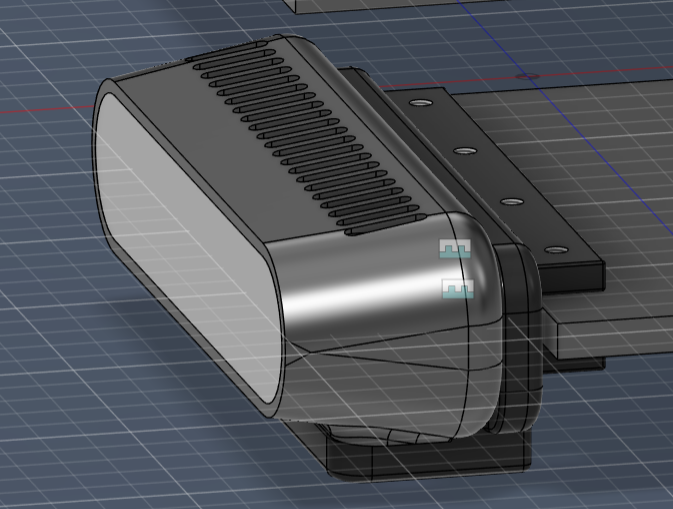
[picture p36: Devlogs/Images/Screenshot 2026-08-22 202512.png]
Finished depth camera mount

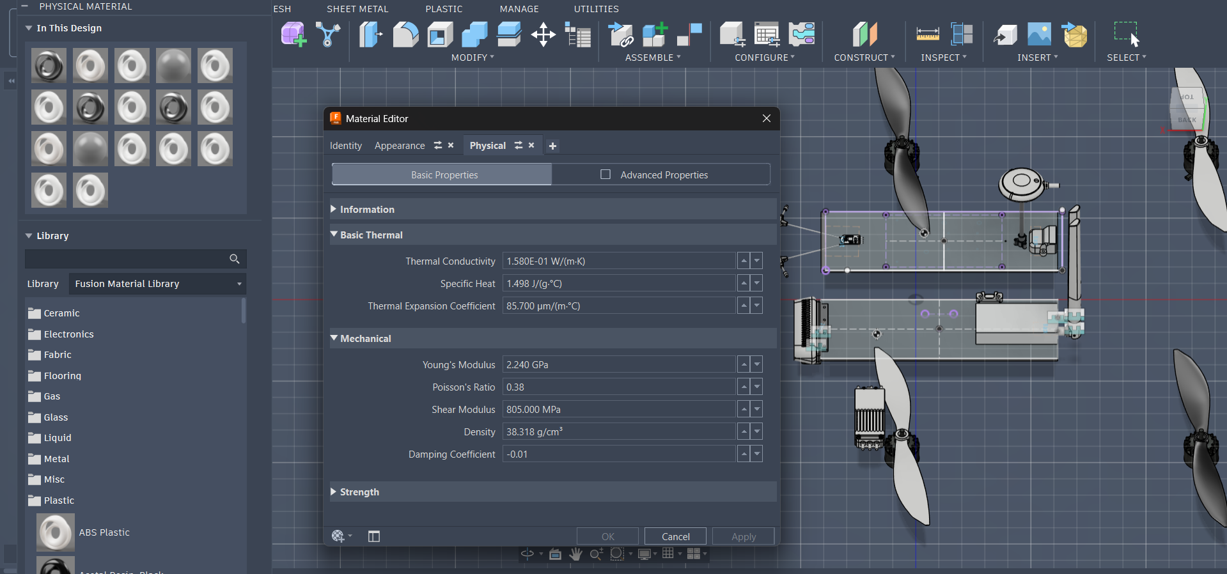
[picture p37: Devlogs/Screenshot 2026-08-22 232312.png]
Custom-density material setup

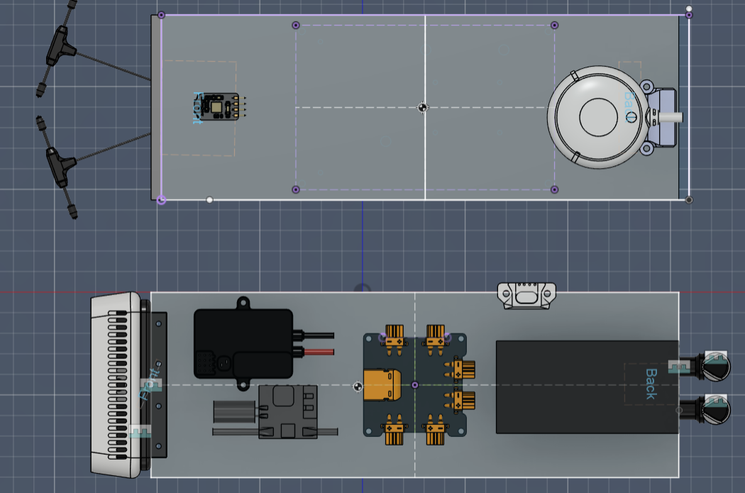
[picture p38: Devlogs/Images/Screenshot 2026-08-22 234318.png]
Centered lower-deck center of mass


The top-deck center of mass is nearly centered. The lower deck was initially offset, but moving the battery improved the alignment. Small ballast weights could be useful for final balancing, but they should be a last resort. It is better to correct the component layout first, especially along the longitudinal axis, where the battery offers a practical adjustment.

## Day 7: Decks and Arm Design

Decks and Arm Design: <https://lapse.hackclub.com/timelapse/D4Xei-P8a743>

I assembled the top and bottom decks and considered several support designs. I chose a tractor configuration because it is more conventional and avoids the additional drag associated with a pusher configuration.

The arms will be integrated with the lower deck while remaining modular enough to replace. I initially considered a true 90-degree X layout, but the depth camera’s field of view made that risky. A wider arm arrangement should reduce the chance of the propellers appearing in the camera’s view.

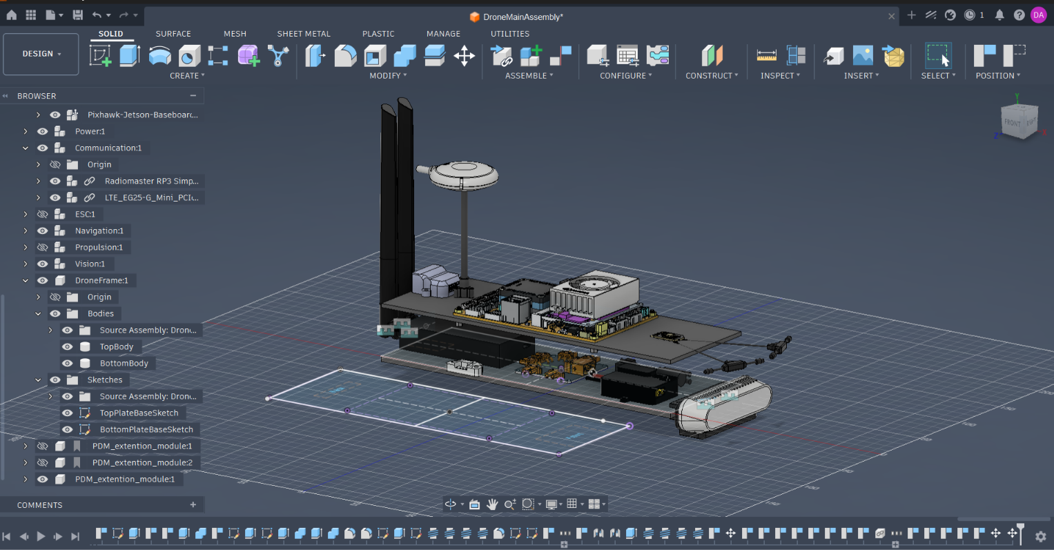
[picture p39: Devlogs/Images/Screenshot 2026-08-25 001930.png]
Assembled frame

First arm attempt
Second arm design

## Day 8: Arms and Motors

Arms and Motors: <https://lapse.hackclub.com/timelapse/MWGjAlClZqYt>

I worked on the arms and motor placement, ensuring that the propellers remain outside the depth camera’s field of view. A computational error in the original sketch made mirroring and positioning difficult, so I created a projection sketch and corrected the geometry.

I also realized that I had accidentally started designing a true X instead of the Deadcat configuration I originally wanted. The corrected approach is to draw the propeller positions and viewing clearances first, then design the arms around them.

## Day 9: Arm Geometry and Center of Mass

Arm Geometry and Center of Mass: <https://lapse.hackclub.com/timelapse/7mI4HmFSVszn>

The first arm layout failed because it did not account for the camera, opposing propellers, and neighboring propellers. I also tried to make all the arms meet at one point, which created unnecessary center-of-mass constraints.

The revised design is a **stretched-rectangle Deadcat** configuration. I started with the propeller positions and angles, then designed the arms around those constraints. This made it easier to keep the camera view clear and avoid propeller overlap.

Neighboring propellers overlapping
Arm layout
Center-of-mass calculation
Preliminary arm

I added motor protection and refined the arm geometry. The motor area needed more width, and the edges needed to be smoother. I also kept a safety margin around the screw holes: the material between a hole and the outer edge should be at least as wide as the hole diameter.

Arm-tip reference
Full arm
Refined arm geometry
Front arms
Complete arm sketch
Arm detail

## Day 10: Rear Arm Geometry and Mirroring

Rear Arm Geometry and Mirroring: <https://lapse.hackclub.com/timelapse/CoAkKe85k_lb>

I modified the frame base to reduce weight and created the rear arm. The rear arms are at different angles relative to the base, so directly mirroring the front arm would not produce the correct motor position. I recreated the basic rear-arm geometry using the correct dimensions and angle, then copied and rotated the more complex features.

Mirrored rear arm

The first rear-arm attempt failed because the alignment and width did not match. The remaining task was to clean the old dimensions and make the arms symmetrical.

## Day 11: Arm Frames and Modular Mounting

Arm Frames and Modular Mounting: <https://lapse.hackclub.com/timelapse/jwxJgQtA3ZOm>  
Arm Frame Plane and Weight Reduction: <https://lapse.hackclub.com/timelapse/I-VWwIf2Bi_W>  
Arm Aerodynamics and Integration: <https://lapse.hackclub.com/timelapse/D9md9M-yNeOV>

After fixing duplicated geometry and several alignment problems, I connected the arm bases. The goal is to make the arms stiff while keeping them swappable. The front and rear arm frames connect to the body, but remain independent enough to remove without disassembling the entire drone.

Right arm plane
Mirrored drone

The arm planes use interlocking notches for alignment while remaining separate parts. I corrected the mirrored geometry, searched for gaps in the sketch, and finished the main arm-plane design.

Finished arm plane
Arm plane, alternate view
Arm plane, bottom view

The remaining work was to add mounting screws and supports for the upper deck.

## Day 12: ESC Integration and Final Frame

ESC Integration and Final Frame: <https://lapse.hackclub.com/timelapse/t7EPD3rolfCb>  
CFD Flow Simulation Test: <https://lapse.hackclub.com/timelapse/_f0_-MtugOYQ>

I added mounting holes and finished connecting the bottom and arm planes.

Mounting holes
Arm-plane mounting
Bottom and arm planes

I had initially forgotten the ESCs, so I redesigned part of the arm to integrate them properly. The ESCs are now mounted, and I started creating the supports for the upper deck and a cover for the RC receiver.

ESCs mounted
Side view
Top view
Side view 2
Lower plane
Arm plane
Side view 3
Front view with LiPo

I added ventilation holes for aerodynamics and cooling, applied the final fillets, and placed the LiPo battery. The main frame is now complete, and the next step is to finish exporting the model and continue with CFD testing.

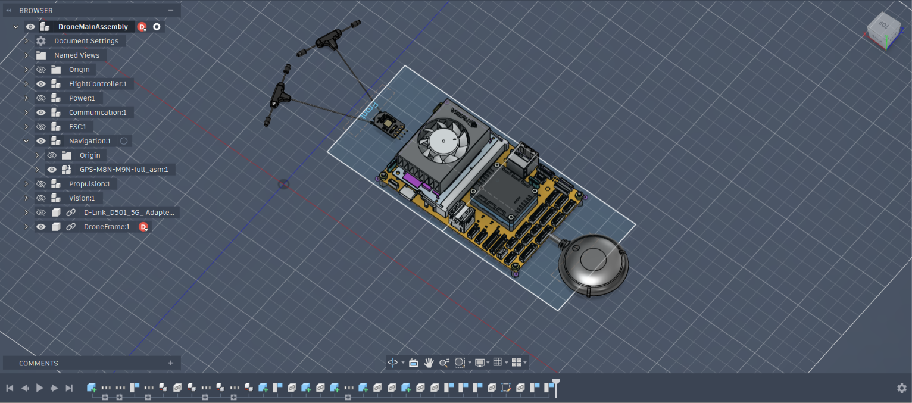
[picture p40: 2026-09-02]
Devlogs/Images/Screenshot 2026-08-08 222519.png

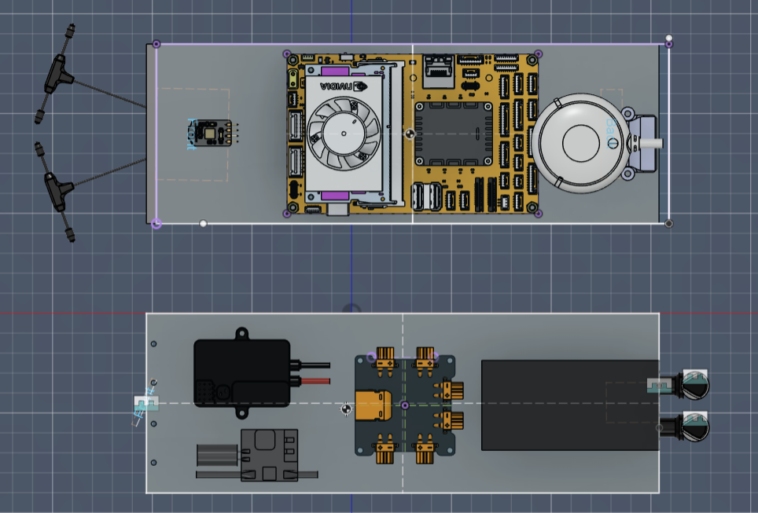
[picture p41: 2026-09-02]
Devlogs/Images/Screenshot 2026-08-22 232843.png

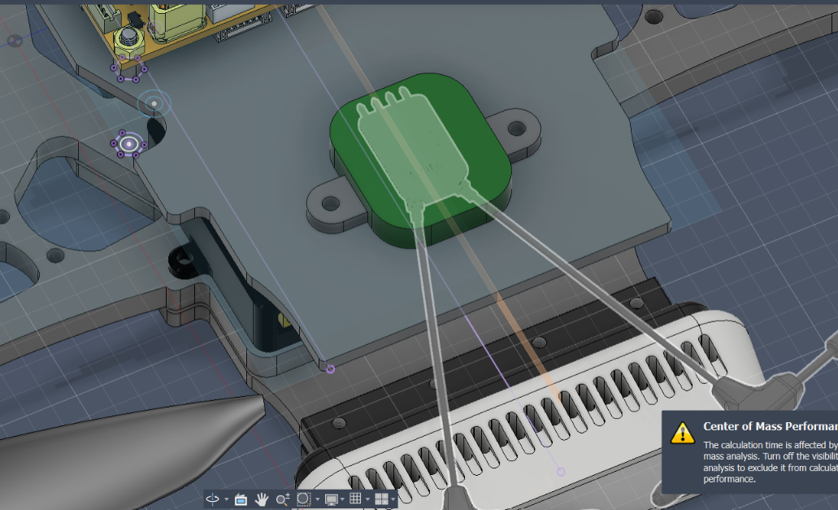
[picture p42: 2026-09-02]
Devlogs/Images/Screenshot 2026-09-02 043004.png

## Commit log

2026-08-05 Added approximate calculations for the drone frame size
    [Components.csv, Thrust.csv]
2026-08-06 Added Weight initial simulation and componnets BoM
    [Components.csv, ComponnetsWeight.csv]
2026-08-06 Made custom symbols in KiCad
    [Components.csv, Drone.kicad_pcb, Drone.kicad_sch]
2026-08-06 Added gitignore, started wiring
    [Drone.kicad_sch]
2026-08-06 Created General Schematics V1, updated componens accordingly
    [Components.csv, Drone.kicad_sch]
2026-08-06 Added devlog for day 2
    [Components.csv]
2026-08-07 Added calculations for motor, props and ESC selection
    [Components.csv, ComponnetsWeight.csv, Drone.kicad_sch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]
2026-08-07 Added main CAD components to LFS
    [11x4.7_pusher_9mm.STEP, 18069A-PDB_asm.stp, BrotherHobby_Tornado_T5_Pro_3113_640.step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]
2026-08-07 Added final components list, devlog and ESC symbol
    [Components.csv]
2026-08-07 Added D-Link D501 5G USB Adapter and Day 3 devlog
    [D-Link_D501_5G_USB_ Adapter.step]
2026-08-08 Switched to design V4
2026-08-08 Updated to more optimized LTE Adapter
    [Components.csv, WiFi Antenna.STEP]
2026-08-08 Top & Bottom Plates, Devlog for Day 4
2026-08-09 Added plates
    [Components.csv, Drone.kicad_sch]
2026-08-09 Placed PMW, Devlog Day 5
    [PDM_extention_module.STEP]
2026-08-22 Added GPS mounting
    [Components.csv]
2026-08-22 Added depth camera mounting
2026-08-28 Addeed main arm base
2026-08-28 Added protection for motors, margins need refinement
2026-08-28 Done with main design for the front arm
2026-08-30 First attempt at Back arm. Asymmetrical. Fail
2026-08-31 Finished the back arm design
2026-09-01 Completed main bottom and arms planes
    [Components.csv]
2026-09-02 Added final source files
    [DroneMainAssemblyStep.step, DroneNoFCAssembly.step]
2026-09-02 Made Components' BoM
    [BoM.csv]
2026-09-02 Formatted additional materials
2026-09-06 Updated README with 3D model and concept board links
